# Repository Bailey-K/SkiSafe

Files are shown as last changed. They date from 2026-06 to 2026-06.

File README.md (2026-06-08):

# SkiSafe

Real-time alpine safety monitoring system. A wearable sensor node worn by the skier transmits telemetry over LoRa to a base-station hub at the lodge, which stores data in SQLite and serves a live web dashboard.

---

## System Architecture

```
Wearable (LoPy4)
  sensors → wearable.py → LoRa TX
                                  ↓
                          Hub LoPy4 (receiver.py)
                          LoRa RX → USB serial
                                  ↓
                          Raspberry Pi
                          reader.py → SQLite DB
                          app.py    → Flask dashboard
```

### Wearable Node

Pycom LoPy4 standalone (no expansion board), battery-powered via Adafruit PowerBoost 1000C. Reads sensors every loop and transmits a JSON packet over LoRa every 5 seconds (2 seconds at alert level 2+).

**Sensors:**

- MPU-6050 IMU — fall detection and immobility monitoring
- BH1750 light sensor — burial detection (sudden darkness after fall)
- NTC thermistor — skin temperature / hypothermia risk
- u-blox NEO-6M GPS — coordinates, speed, altitude

**Outputs:**

- RGB LEDs (alert state indicator)
- Passive piezo buzzer (alert audio)
- Tactile button (local alert dismiss)

### Hub Node

Pycom LoPy4 in a Pytrack expansion board, connected via USB to the Raspberry Pi. Runs `receiver.py` — listens for LoRa packets and prints them to serial.

### Raspberry Pi

Runs two processes (managed via tmux):

- `reader.py` — reads serial from the hub LoPy4, parses JSON telemetry, writes to SQLite
- `app.py` — Flask web dashboard served locally (and optionally via ngrok tunnel)

---

## Alert Levels

| Level  | Trigger | Response |
| --- | --- | --- |
| **L0** | Normal | Green LED steady, silent |
| **L1** | Low battery / cold skin / immobility 30s | Yellow LED, short pip every 2s |
| **L2** | Fall detected / immobility 60s | Red LED, urgent beep, dashboard warning |
| **L3** | L2 unacknowledged for 60s / burial / extreme cold | SOS flash + rapid beep, dashboard SOS, email alert |

Button press or hub ACK clears the buzzer and fall latch at any level.

---

## Repository Structure

```
├── Wearable/
│   ├── wearable.py                   # Production firmware (flash as main.py)
│   └── Component-Testing/
│       ├── hardware_test.py          # Full bring-up validation (PASS/FAIL/WARN)
│       ├── bh1750_test.py
│       ├── mpu6050_test.py
│       ├── ntc_test.py
│       ├── gps_lora_test.py
│       ├── sender_lora_test.py
│       └── receiver_lora_test.py
│
├── Hub/
│   ├── receiver.py                   # Runs on hub LoPy4 — LoRa RX → serial
│   ├── reader.py                     # Runs on Pi — serial → SQLite
│   ├── app.py                        # Runs on Pi — Flask dashboard
│   ├── requirements.txt
│   ├── templates/
│   │   ├── dashboard.html
│   │   └── review.html
│   └── scripts/
│       ├── start_hub.sh
│       ├── stop_hub.sh
│       ├── status_hub.sh
│       └── update-skisafe.sh
│
├── Hardware/
│   ├── pinout_mapping.md             # Full pin reference + circuit details
│   └── breadboard_layout.md         # Breadboard wiring guide
│
└── CAD/
    ├── v1/                           # SolidWorks + STEP files, version 1
    └── v2/                           # SolidWorks + STEP files, version 2
```

---

## Flash Commands

**Wearable firmware:**

```
uvx mpremote connect COM10 cp Wearable/wearable.py :main.py + reset + repl
```

**Hub receiver (one-time, run from project root):**

```
uvx mpremote connect /dev/ttyACM0 cp Hub/receiver.py :main.py + reset
```

---

## Hub Setup (Raspberry Pi)

```bash
# Install dependencies
pip install -r Hub/requirements.txt

# Start both processes in tmux
tmux new-session -d -s reader 'python3 ~/skisafe/reader.py'
tmux new-session -d -s app    'python3 ~/skisafe/app.py'

# Or use the helper scripts
bash Hub/scripts/start_hub.sh
bash Hub/scripts/status_hub.sh
```

Dashboard runs at `http://<pi-ip>:5000`.

---

## Hardware Notes

- **Power:** PowerBoost 1000C 5V → LoPy4 VIN only. All sensors run from LoPy4 3V3. Never connect 5V to any sensor or GPIO pin.
- **LoRa conflict:** P5–P12 on the LoPy4 conflict with the internal LoRa SPI bus and must not be used as GPIO outputs. Use P2–P4 and P21–P23 instead.
- **I2C:** MPU-6050 @ 0x68 (AD0→GND), BH1750 @ 0x23 (ADDR→3V3 via 10kΩ). Shared bus on P9/P10.
- **GPS:** NEO-6M — 3.3V only. One module was destroyed by 5V exposure.

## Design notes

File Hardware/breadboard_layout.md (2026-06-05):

# SkiSafe — Breadboard-Specific Layout & Wiring Guide

## SMALL BOARD — 30 Columns

### Component Placement Overview

| Component | Header row(s) | Columns  | Notes |
| --- | --- | --- | --- |
| LoPy4 | **c** (top header) and **h** (bottom header) | 1 – 14 | Module body spans rows c → h across the gap |
| 100 kΩ resistor #1 (BAT top) | **b** (top half) | 15 & 18  | Legs at b15 and b18, two-hole gap (cols 16–17 empty). b15 = BAT+ input. b18 = P15 midpoint. No polarity. |
| 100 kΩ resistor #2 (BAT bottom) | **b** (top half) | 18 & 21  | Legs at b18 and b21, two-hole gap (cols 19–20 empty). b18 = P15 midpoint (shared with R1). b21 = GND. No polarity. |
| Adafruit PowerBoost 1000C | **a** (pins in top half) | 23 – 30  | USB charging connector end at col 30; 5V out at col 23 |
| USB-to-UART adapter | **f** (pins in bottom half) | ~25 – 30 | TXD at **f28** (use h28), GND at **f29** (use h29). RXD is adjacent — check silkscreen. |

> **Wiring access rule — important:**  
> The LoPy4 module body physically covers rows **d, e** (top half) and **f, g** (bottom half) in cols 1–14.  
> Those rows are inaccessible for wiring under the module.  
> • To connect to the **top header** (row c): place jumper wires in rows **a or b**, same column.  
> • To connect to the **bottom header** (row h): place jumper wires in rows **i or j**, same column.  
> • PowerBoost pins are in row a — use rows **b, c, d, or e** (same column) for wire connections.  
> • USB-UART pins are in row f — use rows **g or h (cols 15–30 only)** for wire connections.

> **Power rule reminder:** PowerBoost 5V → LoPy4 VIN only.  
> LoPy4 3V3 output → large board (+) rail → all sensors. Never connect 5V to sensors.

---

### LoPy4 — Pin Reference Table

The LoPy4 sits directly in the breadboard. Header pins: **top header in row c, bottom header in row h**.

| Col | Row c — Top Header | Row h — Bottom Header | Active Signal / Notes |
| --- | --- | --- | --- |
| 1 | P13 ⚠ input-only | P12 | (spare) |
| 2 | **P14** ⚠ input-only (NTC ADC)  | P11 | NTC ADC in ← large board / (spare) |
| 3 | **P15** ⚠ input-only (batt ADC) | **P10** (I2C SCL) | Batt ADC in ← large board / SCL → large board (hardware SCL) |
| 4 | P16 ⚠ input-only | **P9** (I2C SDA) | SDA → large board (hardware SDA) |
| 5 | P17 ⚠ input-only | P8 | (spare) |
| 6 | P18 ⚠ input-only | P7 | (spare) |
| 7 | **P19** (GPS UART1 RX) | P6 | GPS NMEA in ← large board / (spare) |
| 8 | P20 | P5 | (spare) |
| 9 | **P21** (buzzer out) | **P4** (red LED out) | Buzzer → large board / Red LED → large board |
| 10  | **P22** (button in) | **P3** (yellow LED out)  | Button ← large board / Yellow LED → large board |
| 11  | P23 | **P2** (green LED out) | (spare) / Green LED → large board |
| 12  | **3V3** (output) | **P1** (UART0 TX0) | 3V3 → T+ rail / P1 → USB-UART RXD |
| 13  | GND | **P0** (UART0 RX0) | Ground → T− rail / P0 ← USB-UART TXD |
| 14  | **VIN** | **RST** | 5V in from PowerBoost / reset |

> ⚠ **P13–P18 are input-only** (ESP32 GPIO34–39 — no internal pullup/pulldown, cannot be used as outputs). P14 and P15 are used as ADC inputs only — this is correct and intentional.
> **P9 = hardware SDA, P10 = hardware SCL.** I2C is initialised on these pins in firmware. P0/P1 = UART0 serial console (REPL + flashing). P5–P8, P11, P12 are spare (avoid using as GPIO outputs — these pins conflict with the LoPy4 internal LoRa SPI bus). P23 is spare.

> Confirm all pin positions against your board's silkscreen before wiring — pin order can vary by board revision.

**Wire access summary for LoPy4 pins:**

| Header | Pin row | Connect jumpers in |
| --- | --- | --- |
| Top header | c | Rows **a** or **b** (same column) |
| Bottom header | h | Rows **i** or **j** (same column) |

---

### PowerBoost 1000C — Pin Reference Table

Positioned in the **top half** (rows a–e), **cols 23–30**. Pins insert into row **a**. USB-C charging connector end sits at col 30.

| Col | Row a | Signal | From | To |
| --- | --- | --- | --- | --- |
| 23  | **5V** (out) | Boosted 5V to LoPy4 VIN | **b23** | **b14** (LoPy4 VIN, top half col 14) |
| 24  | GND | PowerBoost ground | **b24** | T− rail |
| 25  | EN | Enable — leave open | — | — |
| 26  | GND | Ground (BAT side) | **b26** | T− rail |
| 27  | LBO | Low battery indicator — leave open | — | — |
| 28  | VS | Battery voltage sense — leave open | — | — |
| 29  | **BAT** | LiPo+ → battery divider | **b29** | **a15** (R1 top leg — use a15 since b15 has the resistor) |
| 30  | USB | Charging input (USB-C) | plug cable in | — |

> The LiPo cell connects via the JST-PH connector on the PowerBoost board — the BAT pin at a29 is the same electrical node as solder pad on the board edge, accessible at b29.

---

### USB-to-UART Adapter — Pin Reference Table

Positioned in the **bottom half** (rows f–j). Pins insert into row **f**. Use rows **g, h, i, or j** in the same column as connection points.

| Col | Row f | Signal | From | To | Purpose |
| ----- | --- | --- | --- | --- | --- |
| 27 | **RXD** | Adapter receive (data **from** LoPy4) | **h27** | **i12** (LoPy4 P1 — UART0 TX0) | See serial print output in terminal |
| 28 | **TXD** | Adapter transmit (data **to** LoPy4)  | **h28** | **i13** (LoPy4 P0 — UART0 RX0) | Send REPL commands to LoPy4 |
| 29 | **GND** | Ground | **h29** | T− rail | Common ground |
| other | 3V3 / 5V / CTS | — | — | **Leave unconnected** | LoPy4 is powered by PowerBoost independently |

> **RXD ← P1 (UART0 TX0):** This wire lets you see everything the LoPy4 prints — sensor readings, errors, REPL/debug output. Open any serial terminal (e.g. PuTTY, Arduino Serial Monitor) at **115200 baud** on your USB-UART's COM port.
> 
> **TXD → P0 (UART0 RX0):** Full bidirectional REPL — type commands and see responses. UART0 *is* the LoPy4's REPL/programming console, so this is also the port mpremote uses to upload code. No GPS conflict: GPS uses UART1 (P19) and the serial console uses UART0 (P0/P1). Both work simultaneously, permanently, no swapping needed.
> 
> **Flashing (uploading code):** Works over this same adapter. Because UART0 is the REPL console, mpremote uploads through P0/P1 — no separate USB needed. Example (run from the project root): `uvx mpremote connect COM10 cp "Wearable/Code/Component-Testing/Full-Hardware_Test.py" :main.py + reset + repl`.
> 
> **Wire routing:** f27 and f29 are occupied by the adapter pins — use h27, h28, h29 (same bottom-half column, same node) as your jumper wire insertion points.  
> P0 and P1 are on the **bottom header, cols 13 and 12** — use i13 (P0) and i12 (P1) as insertion points.  
> In firmware: nothing to initialise — print() output and the REPL/mpremote both use the default UART0 console automatically.

---

### Battery Voltage Divider — on the Small Board

> Two 100 kΩ resistors at cols 15–21 (row b). R1 legs at b15 and b18; R2 legs at b18 and b21. b15 is occupied by the resistor leg — wire to **a15** (same node). Midpoint at b18 → P15 (wire S5). R2 far end at b21 is occupied — wire to **c21** (same node) → GND (wire S6). See S1–S11 in the Complete Wire Map.

---

## LARGE BOARD — 63 Columns (split into two halves for readability)

### Component Placement Overview

| Component | Type | Insert row | Columns | Orientation / notes |
| --- | --- | --- | --- | --- |
| MPU-6050 (GY-521) | 8-pin single-row breakout | **c** (top half) | 2 – 9 | Col 2=INT, 3=ADD, 4=XCL, 5=XDA, 6=SDA, 7=SCL, 8=GND, 9=VCC. ADD (col 3) wired to GND for address 0x68. Wires in row e. |
| BH1750 (GY-302) | 5-pin single-row breakout | **c** (top half) | 12 – 16 | Col 12=VCC, 13=SCL, 14=SDA, 15=ADD, 16=GND. ADD (col 15) connected to B+ (3V3) rail via a 10 kΩ current-limiting resistor to bypass an internal board short. Sets hardware address to 0x23. |
| NEO-6M GPS module | 4-pin header (large PCB overhangs) | **a** (top half) | 21 – 24 | Col 21=VCC, 22=RX (leave open), 23=TX, 24=GND. Antenna faces back. Wires in row e. |
| 10 kΩ fixed resistor (NTC series) | Through-hole resistor | **a** (top half) | 31 & 33 | Legs in a31 and a33. Bridges col 32. No polarity. The junction at col 31 is the ADC node shared with the NTC. |
| 10 kΩ NTC thermistor | Through-hole thermistor | **c** (top half) | 31 – 32 | Legs in c31 and c32. Col 31 = ADC node (electrically joined to a31 — same column, same half). Col 32 leg wired to GND. Body extended on a short lead for wrist contact. |
| Green LED | 5 mm LED (3 holes wide) | **h** (bottom half) | 48, 49 (body), 50 | **Anode (long leg) at h50**, cathode (short leg) at h48. Body over h49 (empty). Signal wire h50 ← small board i8 (P5). Resistor j48 → B− rail. |
| Yellow LED | 5 mm LED (3 holes wide) | **h** (bottom half) | 44, 45 (body), 46 | **Anode (long leg) at h46**, cathode (short leg) at h44. Body over h45 (empty). Signal wire h46 ← small board i7 (P6). Resistor j44 → B− rail. |
| Red LED | 5 mm LED (3 holes wide) | **h** (bottom half) | 40, 41 (body), 42 | **Anode (long leg) at h42**, cathode (short leg) at h40. Body over h41 (empty). Signal wire h42 ← small board i6 (P7). Resistor j40 → B− rail. |
| 220 Ω resistor — green LED | Through-hole resistor | **j** (bottom half) | 48 | j48 → B− rail. No polarity. |
| 220 Ω resistor — yellow LED | Through-hole resistor | **j** (bottom half) | 44 | j44 → B− rail. No polarity. |
| 220 Ω resistor — red LED | Through-hole resistor | **j** (bottom half) | 40 | j40 → B− rail. No polarity. |
| Piezo buzzer | Passive piezo disc | **a** and **c** (top half, diagonal) | 55 (+), 57 (−) | Positive (+) leg at **a55**, negative (−) leg at **c57**. Diagonal placement due to body shape. Both legs in top half — no gap crossing needed. |
| Tactile button | Momentary switch | **i** (bottom half) | 59 & 61 | Legs at **i59** (GND) and **i61** (signal). Wires connect at j59 (GND) and j61 (signal). Pressing bridges cols 59 and 61. |

> **Polarity reminders:**  
> — LEDs: long leg = anode (+), short leg = cathode (−). Inserting backwards = no light, no damage.  
> — Buzzer: marked (+) = positive. Inserting backwards = no sound.  
> — Resistors and NTC: no polarity — insert either way.  
> — GPS module: **3.3V VCC only** — double check before powering on.

---

### Component-by-Component Wiring

### MPU-6050 — Cols 2–9, Row c

The MPU-6050 has **8 pins in a single row**. Insert into row **c**. Wires connect in row **e** (same top-half node).

| From | To | Signal |
| --- | --- | --- |
| 3V3 rail (B+) | **e9** (MPU VCC) | 3.3V power |
| **e8** (MPU GND) | GND rail (B−) | Ground |
| **e7** (MPU SCL) | **c13** (BH SCL — shared channel to LoPy4 P10) | I2C clock via daisy-chain |
| **e6** (MPU SDA) | **c14** (BH SDA — shared channel to LoPy4 P9)  | I2C data via daisy-chain  |
| c5 XDA | — | Not connected |
| c4 XCL | — | Not connected |
| **e3** (MPU ADD) | GND rail (B−) | Set I2C address 0x68 |
| c2 INT | — | Not connected |

---

### BH1750 — Cols 12–16, Row c

The BH1750 has **5 pins in a single row**. Insert into row **c**. Wires connect in row **e** (same top-half node).

| From | To | Signal |
| --- | --- | --- |
| 3V3 rail (B+) | **e12** (BH VCC) | 3.3V power |
| **e13** (BH SCL) | Small board **i3** (P10, SCL) | I2C clock |
| **e14** (BH SDA) | Small board **i4** (P9, SDA)  | I2C data |
| **3V3** rail (B+) via 10 kΩ Resistor | e15 (BH ADD) | Safely address pull-up (yields address 0x23) |
| **e16** (BH GND) | GND rail (B−) | Ground |

> **I2C daisy-chain:** The inter-board wires from the LoPy4 (I3/I4) land at c14 (BH SDA) and c13 (BH SCL). Jumper wires L4/L5 connect those same columns at e6 (MPU SDA) and e7 (MPU SCL) — placing both sensors on the same I2C lines. The BH1750 output wires (e13→i3, e14→i4) carry the signal back to the LoPy4.
> The breakout boards include on-board pull-up resistors — do not add extra ones.

---

### NEO-6M GPS Module — Cols 21–24, Row a

Wires connect in row **e** (node in row a).

| From | To | Signal |
| --- | --- | --- |
| 3V3 rail (B+) | **e21** (GPS VCC) | 3.3V power **(NEVER 5V)** |
| a22 GPS RX | — | Leave unconnected |
| **e23** (GPS TX)  | Small board **b7** (LoPy4 P19) | GPS NMEA data |
| **e24** (GPS GND) | GND rail (B−) | Ground |

> **⚠ 3.3V only.** Double-check before powering on.

---

### NTC Thermistor Circuit — Cols 31–33

This is a voltage divider built from two components: a fixed 10 kΩ resistor and the NTC thermistor. The NTC is fragile — handle legs carefully and don't flex them repeatedly.

```
  Circuit:  3V3 → [10kΩ fixed] → P14 (ADC node) → [10kΩ NTC] → GND
```

**Physical layout:** The fixed resistor sits in row **a** (legs at a31 and a33, bridging col 32). The NTC sits in row **c** (legs at c31 and c32). Because rows a–e in the same column are all connected, **a31 and c31 are the same electrical node** — that junction is the P14 ADC midpoint. No bridge wire needed between them; the breadboard does it internally.

| From | To | Signal | Notes |
| --- | --- | --- | --- |
| 3V3 rail (B+) | **b33** (resistor top leg) | 3.3V supply into divider | a33 = b33 (same top-half column) |
| **b31** (ADC node / resistor bottom leg = NTC top leg) | Small board **b2** (LoPy4 P14) | NTC ADC signal | a31 = b31 = c31 — all same node  |
| **b32** (NTC bottom leg) | GND rail (B−) | Divider GND | c32 = b32 — same node |
| Resistor legs | a31 & a33 | 10 kΩ fixed (bridges col 32) | — |
| Thermistor legs | c31 & c32 | 10 kΩ NTC | — |

---

### LED Bank — Cols 40–49

The 220 Ω resistor sits between the cathode and the B− GND rail 

#### Green LED (P2) — Cols 48, & 50

| From | To | Signal |
| --- | --- | --- |
| Small board **i11** (P2) | Large board **h50** | P2 GPIO signal |
| **h50** | — | LED anode, long leg inserted here |
| **h48** | — | LED cathode, short leg inserted here |
| **j48** | **B− rail** | 220 Ω resistor (cathode → GND) |

#### Yellow LED (P3) — Cols 44, & 46

| From | To | Signal |
| --- | --- | --- |
| Small board **i10** (P3) | Large board **h46** | P3 GPIO signal |
| **h46** | — | LED anode, long leg inserted here |
| **h44** | — | LED cathode, short leg inserted here |
| **j44** | **B− rail** | 220 Ω resistor (cathode → GND) |

#### Red LED (P4) — Cols 40, & 42

| From | To | Signal |
| --- | --- | --- |
| Small board **i9** (P4) | Large board **h42** | P4 GPIO signal |
| **h42** | — | LED anode, long leg inserted here |
| **h40** | — | LED cathode, short leg inserted here |
| **j40** | **B− rail** | 220 Ω resistor (cathode → GND) |

> **LED polarity:** Long leg = anode (+). Short leg = cathode (−).

---

### Piezo Buzzer — Col 55 (+), Col 57 (−), diagonal

Direct GPIO drive from P21 at 3.3V. Placed diagonally.

| From | To | Signal |
| --- | --- | --- |
| Small board **b9** (LoPy4 P21) | **b55** (= a55, buzzer positive) | P21 GPIO signal |
| **b57** (= c57, buzzer negative) | GND rail (B−) | Ground |

---

### Dismiss Button — Cols 59 & 61

Tactile momentary switch, active LOW with PULL_UP. Entirely in the bottom half.

| From | To | Signal |
| --- | --- | --- |
| Small board **b10** (LoPy4 P22) | **j61** (button signal leg) | P22 GPIO signal |
| **j59** (button GND leg) | B− rail | Ground (active-LOW when pressed) |

---

## Complete Wire Map

Every wire in the system listed with exact breadboard reference.

### Small Board — Internal Wires

| # | From | To | Signal |
| --- | --- | --- | --- |
| S1  | **b23** (PowerBoost 5V)  | **b14** (LoPy4 VIN) | 5V power |
| S2  | **b24** (PowerBoost GND) | T− rail | Ground |
| S3  | **b26** (PowerBoost GND) | T− rail | Ground |
| S4  | **b29** (PowerBoost BAT) | **a15** (R1 top leg — b15 is occupied by the resistor, a15 is same node) | LiPo+ into bat divider |
| S5  | **a18** (R1/R2 midpoint) | **b3** (LoPy4 P15) | Battery ADC signal |
| S6  | **c21** (R2 bottom leg)  | T− rail | Divider GND |
| S7  | **b12** (LoPy4 3V3) | T+ rail | 3.3V supply |
| S8  | **b13** (LoPy4 GND) | T− rail | Ground |
| S9  | **h29** (USB-UART GND) | T− rail | Ground |
| S10 | **h27** (USB-UART RXD) | **i12** (LoPy4 P1, UART0 TX0) | Serial + REPL output — LoPy4 → terminal |
| S11 | **h28** (USB-UART TXD) | **i13** (LoPy4 P0, UART0 RX0) | REPL / flash upload — terminal → LoPy4  |

### Inter-Board Wires (Small Board → Large Board)

| # | From (small board) | To (large board) | Signal |
| --- | --- | --- | --- |
| I1  | T+ rail | B+ (3V3) rail | 3.3V power |
| I2  | T− rail | GND (B−) rail | Ground |
| I3  | **i4** (LoPy4 P9, SDA) | **c14** (BH SDA), daisy-chained over to**e6** (MPU SDA) | I2C data |
| I4  | **i3** (LoPy4 P10, SCL) | **c13** (BH SCL), daisy-chained over to**e7** (MPU SCL) | I2C clock |
| I5  | **b7** (LoPy4 P19, GPS RX) | **e23** (GPS TX) | GPS NMEA |
| I6  | **b2** (LoPy4 P14, NTC ADC) | **b31** (NTC ADC node) | NTC temperature |
| I7  | **i11** (LoPy4 P2, green LED)  | **h50** (green LED anode) | Green LED signal  |
| I8  | **i10** (LoPy4 P3, yellow LED) | **h46** (yellow LED anode) | Yellow LED signal |
| I9  | **i9** (LoPy4 P4, red LED) | **h42** (red LED anode) | Red LED signal |
| I10 | **b9** (LoPy4 P21, buzzer) | **b55** (= a55, buzzer positive) | Buzzer drive |
| I11 | **b10** (LoPy4 P22, button) | **j61** (button leg 1) | Button signal |

### Large Board — Internal Wires

| # | From | To | Signal |
| --- | --- | --- | --- |
| L1  | B+ (3V3) rail | **e9** (MPU VCC) | 3.3V to MPU-6050 |
| L2  | **e8** (MPU GND) | B− rail | MPU-6050 ground |
| L3  | **e3** (MPU ADD) | B− rail | MPU I2C address = 0x68 |
| L4  | **e6** (MPU SDA) | **c14** (BH SDA) | SDA daisy-chain between sensors |
| L5  | **e7** (MPU SCL) | **c13** (BH SCL) | SCL daisy-chain between sensors |
| L6  | B+ (3V3) rail | **e12** (BH VCC) | 3.3V to BH1750 |
| L7  | **e15** (BH ADD) | B+ (3V3) rail via 10k Ω Resistor | Safety bypass: locks BH1750 address to 0x23 |
| L8  | **e16** (BH GND) | B− rail | BH1750 ground |
| L9  | B+ (3V3) rail | **e21** (GPS VCC) | 3.3V to GPS ⚠ NEVER 5V |
| L10 | **e24** (GPS GND) | B− rail | GPS ground |
| L11 | B+ (3V3) rail | **b33** (NTC fixed R top) | 3.3V into NTC divider |
| L12 | **b32** (NTC GND leg) | B− rail | NTC divider ground |
| L13 | **j40** (red LED cathode) | B− rail | Red LED GND return via 220 Ω |
| L14 | **j44** (yellow LED cathode) | B− rail | Yellow LED GND return via 220 Ω |
| L15 | **j48** (green LED cathode)  | B− rail | Green LED GND return via 220 Ω |
| L16 | **b57** (buzzer negative) | B− rail | Buzzer ground |
| L17 | **j59** (button GND leg) | B− rail | Button ground (active-LOW) |

> **Totals: 11 small-board internal + 11 inter-board + 17 large-board internal = 39 wires.**
> L4 and L5 are the only inter-sensor jumpers on the large board (I2C daisy-chain).
> Battery divider is fully on the small board — no inter-board wires for P15 or BAT.

---

## Pre-Power Checklist

Before applying power for the first time:

- [ ] LoPy4 VIN connected to PowerBoost 5V — **not** to 3V3
- [ ] GPS VCC connected to 3V3 rail — **not** to 5V or LoPy4 VIN
- [ ] MPU-6050 AD0 connected to GND (not floating)
- [ ] NTC circuit: 3V3 → 10kΩ → P14 node → NTC → GND (NTC on bottom)
- [ ] Battery divider: BAT+ → 100kΩ → P15 node → 100kΩ → GND
- [ ] All three LED cathodes (short leg) to GND rail
- [ ] LED anodes (long leg) away from GND, toward resistors
- [ ] Buzzer polarity: (+) to P21 (b9), (−) to GND
- [ ] Button: P22 (b10) → j61 (signal leg); j59 → GND
- [ ] Large board B+ connected to small board B+ (3V3 inter-board)
- [ ] Large board B− connected to small board B− (GND inter-board)
- [ ] I2C: P9 (i4) → SDA daisy-chain (c14 ↔ e6); P10 (i3) → SCL daisy-chain (c13 ↔ e7)
- [ ] USB-UART on P0/P1 (UART0 console) — GPS on P19 (UART1) — no conflict
- [ ] BH1750 ADD connected to 3V3 rail via 10 kΩ resistor (Bypasses address pin ground short)
- [ ] I2C scan returns `[0x23, '0x68']` before flashing production firmware

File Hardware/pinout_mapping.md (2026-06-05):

# SkiSafe — Hardware Pinout & Wiring Reference
**Board:** Pycom LoPy4 (standalone, no expansion board)  
**Runtime:** Pycom MicroPython 1.20.2.r6  

---

## ⚠ Critical Power Rules

> **The 5V rail (PowerBoost 1000C output) connects ONLY to LoPy4 VIN.**  
> Every sensor, module, LED, and buzzer runs from LoPy4 **3V3** only.  
> Connecting any LoPy4 GPIO or sensor directly to 5V WILL destroy it.  
> The NEO-6M GPS was destroyed once by 5V exposure — do not repeat.

> **Never disconnect or reconnect sensors while powered.**  
> The LoPy4 ADC inputs are not 5V tolerant and have limited ESD protection.

---

## LoPy4 Pin Assignment — Complete

| LoPy4 Pin | Direction | Connected To | Signal | Notes |
|---|---|---|---|---|
| **P2**  | Output | Green LED → 220 Ω → GND | Status LED green | Alert level 0 = normal |
| **P3**  | Output | Yellow LED → 220 Ω → GND | Status LED yellow | Alert level 1 = warning |
| **P4**  | Output | Red LED → 220 Ω → GND | Status LED red | Alert level 2 = fall / SOS |
| **P9**  | I2C SDA | MPU-6050 SDA + BH1750 SDA | I2C data | Hardware SDA. Shared bus — both devices on same wires. |
| **P10** | I2C SCL | MPU-6050 SCL + BH1750 SCL | I2C clock | Hardware SCL. Shared bus. |
| **P21** | Output | Piezo buzzer (+) → GND | Alert buzzer | Active HIGH. Non-blocking pattern in firmware. |
| **P22** | Input  | Tactile button → GND | Alert dismiss | `PULL_UP`, active LOW. Idle = HIGH. Press = LOW. |
| **P14** | ADC in | NTC thermistor (GND-side of divider) | Skin temperature | `ATTN_11DB` (0–3.6V). 10 kΩ NTC from P14→GND, 10 kΩ series from 3V3→P14. |
| **P15** | ADC in | Battery divider midpoint | Battery % monitor | `ATTN_11DB`. 100 kΩ from LiPo+→P15, 100 kΩ from P15→GND. V_pin = V_bat/2. |
| **P19** | UART1 RX | NEO-6M GPS TX | GPS NMEA receive | Data flows GPS→LoPy4. |
| **P0**  | UART0 RX0 | USB-UART adapter TXD | Serial console in | REPL input / mpremote code upload, 115200 baud. |
| **P1**  | UART0 TX0 | USB-UART adapter RXD | Serial console out | REPL + print()/debug output, 115200 baud. |

> ⚠ **P13–P18 are input-only** (ESP32 GPIO34–39 — no internal pullup/pulldown, cannot drive outputs). P14 and P15 are intentionally used as ADC inputs only.
> ⚠ **P5–P12 conflict with the LoPy4 internal LoRa SPI bus** — do not use as GPIO outputs. Initialising any of these as Pin.OUT silently breaks LoRa TX (confirmed by hardware testing June 2026). Use P2–P4, P21–P23 for GPIO outputs instead.

### Firmware declaration reference
```python
# I2C shared bus — hardware pins (MPU-6050 @ 0x68, BH1750 @ 0x23)
i2c = I2C(0, pins=('P9', 'P10'))

# GPS UART1 — P19=RX only
gps_uart = UART(1, baudrate=9600, pins=(None, 'P19'))

# Debug / REPL console — default UART0 on P0 (RX0) / P1 (TX0), 115200 baud.
# Nothing to initialise: print() output and the REPL/mpremote use UART0 automatically.

# ADC channels
adc       = ADC()
ntc_chan  = adc.channel(pin='P14', attn=ADC.ATTN_11DB)
batt_chan = adc.channel(pin='P15', attn=ADC.ATTN_11DB)

# Outputs
buzzer     = Pin('P21', mode=Pin.OUT, value=0)
led_green  = Pin('P2',  mode=Pin.OUT, value=0)
led_yellow = Pin('P3',  mode=Pin.OUT, value=0)
led_red    = Pin('P4',  mode=Pin.OUT, value=0)

# Input
button = Pin('P22', mode=Pin.IN, pull=Pin.PULL_UP)   # active LOW
```

---

## I2C Bus — Shared Devices

| Device | I2C Address | ADDR Pin | Pull-up Resistors |
|---|---|---|---|
| MPU-6050 (IMU) | `0x68` | AD0 → GND | Breakout has on-board 4.7 kΩ pull-ups on SDA/SCL |
| BH1750 (Light) | `0x46` | ADDR → 3V3 | Breakout has on-board pull-ups |

```
3V3 ──┬── MPU-6050 VCC              3V3 ──┬── BH1750 VCC
      │                                   │
P9  ──┼── MPU-6050 SDA              P9  ──┼── BH1750 SDA
P10 ──┼── MPU-6050 SCL              P10 ──┼── BH1750 SCL
      │                                   │
GND ──┴── MPU-6050 GND              GND ──┴── BH1750 GND
GND ───── MPU-6050 AD0              3V3 ───── BH1750 ADDR
```

> Both sensors share the same SDA and SCL lines. The MPU-6050 SDA/SCL wires connect into the same nodes as the BH1750 SDA/SCL — the breadboard/perfboard junction carries signal from both sensors to the LoPy4 on P9/P10.

Verify I2C bus with:
```python
from machine import I2C
i2c = I2C(0, pins=('P9', 'P10'))
print([hex(d) for d in i2c.scan()])
# Expected: ['0x46', '0x68']
```

---

## GPS Module (GY-NEO6MV2 / u-blox NEO-6M)

| GPS Pin | Connects To | Notes |
|---|---|---|
| VCC | LoPy4 **3V3** | **3.3V ONLY — 5V will destroy the module (confirmed once).** |
| GND | GND | Common ground |
| TX | LoPy4 **P19** | GPS sends NMEA sentences → LoPy4 UART1 RX |
| RX | **LEAVE OPEN** | No commands sent to GPS. |

```
NEO-6M module
┌──────────┐
│ VCC ─────┼──── 3V3
│ GND ─────┼──── GND
│ TX  ─────┼──── P19  (LoPy4 UART1 RX)
│ RX  ─────┼──── (nothing)
└──────────┘
```

**UART config:** 9600 baud, 8N1  
**Sentences parsed:** `$GPRMC` / `$GNRMC` (position, speed, validity), `$GPGGA` / `$GNGGA` (altitude, satellite count)  
**Fix indicator:** TIMEPULSE LED on the breakout board blinks at 1 Hz once a fix is acquired  
**Cold start time:** 1–15 minutes outdoors; indoor fix with ceramic patch antenna is unreliable

---

## NTC Thermistor Circuit (Skin Temperature — P14)

```
3V3 ──── 10 kΩ (series, fixed) ──── P14 (ADC) ──── 10 kΩ NTC ──── GND
```

- NTC is on the **GND side** (bottom) of the voltage divider  
- Higher temperature → lower NTC resistance → lower voltage at P14 → lower ADC raw value  
- `ATTN_11DB` sets full-scale ≈ 3.6V, raw range 0–4095  
- Steinhart-Hart Beta: **B = 3950**, T₀ = 25°C, R₀ = 10 kΩ  
- Sentinel: raw ≤ 10 or ≥ 4085 → open/short detected → firmware returns −99.0°C  
- Valid skin range: approximately 15°C – 40°C in field use  
- NTC body sits against the inner wrist strap for skin contact

---

## Battery Monitor Circuit (P15)

```
LiPo+ (BAT pin) ──── 100 kΩ ──── P15 (ADC) ──── 100 kΩ ──── GND
```

- Equal-value divider: V_P15 = V_bat / 2  
- LiPo range: 3.3V (empty) → 4.2V (full) → P15 sees 1.65V → 2.10V  
- `ATTN_11DB` comfortably covers this range with no risk of exceeding 3.6V  
- Formula: `batt_pct = (V_bat − 3.3) / (4.2 − 3.3) × 100`, clamped 0–100  
- BAT pin is the output of the PowerBoost 1000C (same node as LiPo positive)

---

## LED Wiring

Each LED uses a **220 Ω** current-limiting series resistor.  
At 3.3V with a typical LED Vf ≈ 2.0V: I = (3.3 − 2.0) / 220 ≈ **6 mA** — safe for LoPy4 GPIO.

```
P2 ──── Green LED anode  ──── cathode ──── 220 Ω ──── GND
P3 ──── Yellow LED anode ──── cathode ──── 220 Ω ──── GND
P4 ──── Red LED anode    ──── cathode ──── 220 Ω ──── GND
```

| Alert Level | Meaning | LED State |
|---|---|---|
| 0 — Normal | All good | Green steady ON, Yellow OFF, Red OFF |
| 1 — Warning | Low battery / cold / immobility warning | Yellow steady ON, Green OFF, Red OFF |
| 2 — Alert | Fall detected / prolonged immobility | Red steady ON, Green OFF, Yellow OFF |
| 3 — SOS | Burial / extreme cold / fall + unconscious | Yellow rapid flash + Red rapid flash, Green OFF |

---

## Buzzer

```
P21 ──── Buzzer positive ──── Buzzer negative ──── GND
```

- Passive piezo, direct GPIO drive at 3.3V (no transistor needed at this current draw)  
- Non-blocking pattern controlled by `update_buzzer()` — uses timestamps, not `sleep()`

| Alert Level | Pattern | Cadence |
|---|---|---|
| 0 — Normal | Silent | — |
| 1 — Warning | Short pip | 100 ms ON / 1900 ms OFF |
| 2 — Fall | Urgent beep | 300 ms ON / 700 ms OFF |
| 3 — SOS | Rapid pulse | 200 ms ON / 200 ms OFF |

**Mute behaviour:** Physical button press OR hub LoRa ACK clears both the buzzer mute flag and the fall detection latch.

---

## Button (Alert Dismiss)

```
P22 ──── one terminal of button
GND ─── other terminal of button
```

- Internal `PULL_UP` enabled — idle state P11 = HIGH (1)  
- Press pulls P11 to GND → LOW (0)  
- Firmware uses 50 ms software debounce  
- Action: mutes buzzer, clears fall detection latch

---

## Power Architecture

```
LiPo cell (3.7V nominal, 1200–2000 mAh)
    │
    ▼
Adafruit PowerBoost 1000C
    │  ← USB-C input for charging (charges while running)
    │
    ├── 5V output ──────────────── LoPy4 VIN            ← ONLY 5V connection
    └── BAT pin ─── 100 kΩ ─── P15 (battery monitor)
                         └─── 100 kΩ ─── GND

LoPy4 VIN (5V) ──── LoPy4 onboard 3.3V regulator
                        │
                        ├── LoPy4 3V3 supply
                        ├── MPU-6050 VCC
                        ├── BH1750 VCC
                        ├── NEO-6M GPS VCC  ← 3.3V only
                        ├── 10 kΩ NTC series resistor (top of divider)
                        └── 100 kΩ battery divider (top resistor)
```

---

## Alert Escalation Logic (Firmware)

| Condition | Alert Level | Hub Action |
|---|---|---|
| Battery < 20% | L1 | Local warning only (no hub action) |
| Skin temp < 15°C | L1 | Local warning only |
| Immobile ≥ 30 s | L1 | Local warning only |
| Immobile ≥ 60 s | L2 | Hub shows ALERT, enables ACK button |
| Fall detected (latch 5 min) | L2 | Hub shows ALERT |
| Skin temp < 10°C | L3 | Hub sends SOS email |
| Burial (dark + immobile ≥ 60 s) | L3 | Hub sends SOS email |
| Fall + immobile ≥ 120 s | L3 | Hub sends SOS email |

**Fall latch:** Once a fall spike is detected, the alert holds at minimum L2 for 5 minutes even if the skier stands up.  
Only a physical button press or a hub LoRa ACK clears the latch early.

---

## LoRa Link (Wearable → Hub)

| Parameter | Value |
|---|---|
| Frequency | 915 MHz |
| Region plan | AU915 |
| Spreading factor | SF7 |
| Bandwidth | 125 kHz |
| Coding rate | 4/5 |
| Preamble | 8 symbols |
| TX power | Default (Pycom LoPy4 max ≈ 20 dBm) |
| Packet size | ~85–100 bytes (JSON) |
| Normal TX cadence | 5 seconds |
| Alert (L2+) TX cadence | 2 seconds |

**Packet format (short keys — matches reader.py KEY_MAP):**
```
{"i":"SK01","c":12,"st":28.3,"lx":1102.4,"la":-37.1522,"lo":146.4418,"al":1707.0,"sp":42.1,"a":0}
```

---

## Hub Node — LoPy4 in Pytrack

| Connection | Detail |
|---|---|
| USB | Pytrack USB-C → Raspberry Pi `/dev/ttyACM0` |
| Serial baud | 115200 |
| LoRa antenna | 915 MHz whip on **bottom-left U.FL** connector of LoPy4 |
| LoRa config | Identical to wearable (915 MHz AU915 SF7 BW_125KHz CR 4/5 preamble 8) |

The hub LoPy4 runs `receiver.py` — receives LoRa packets and prints them to serial in the format `reader.py` expects:
```
Received: {"i":"SK01","c":12,...}
RSSI: -72
SNR: 8.5
```

---

## Component I2C Address Reference

| Address | Device | Config |
|---|---|---|
| `0x68` | MPU-6050 IMU | AD0 → GND (default) |
| `0x69` | MPU-6050 (alt) | AD0 → 3V3 — not used |
| `0x46` | BH1750 light sensor | ADDR → 3V3 |
| `0x23` | BH1750 (alt) | ADDR → GND or floating — not used |

---

## Bill of Materials — Prototype

| Qty | Component | Value / Part | Notes |
|-----|---|---|---|
| 1 | Pycom LoPy4 | — | Standalone — no expansion board |
| 1 | MPU-6050 breakout | GY-521 | I2C, AD0 → GND |
| 1 | BH1750 breakout | GY-302 | I2C, ADDR → 3V3 |
| 1 | GPS module | GY-NEO6MV2 (u-blox NEO-6M) | **3.3V VCC only** |
| 1 | NTC thermistor | 10 kΩ, B=3950 | Skin contact sensor |
| 1 | Fixed resistor | 10 kΩ | NTC series / divider top |
| 2 | Fixed resistor | 100 kΩ | Battery voltage divider |
| 3 | Fixed resistor | 220 Ω | LED current limiting |
| 1 | Green LED | 3mm or 5mm | Status level 0 |
| 1 | Yellow LED | 3mm or 5mm | Status level 1 |
| 1 | Red LED | 3mm or 5mm | Status level 2 |
| 1 | Piezo buzzer | Passive, 3V–5V | P21 direct drive |
| 1 | Tactile button | Momentary NO | Dismiss / mute |
| 1 | Adafruit PowerBoost 1000C | — | USB-C charge + 5V boost |
| 1 | LiPo battery | 3.7V, 1200–2000 mAh | Connected to PowerBoost |
| 1 | LoRa antenna | 915 MHz whip | On LoPy4 U.FL |
| 1 | USB-to-UART adapter | CP2102 or similar | UART0 console / REPL / flashing (P0/P1) |

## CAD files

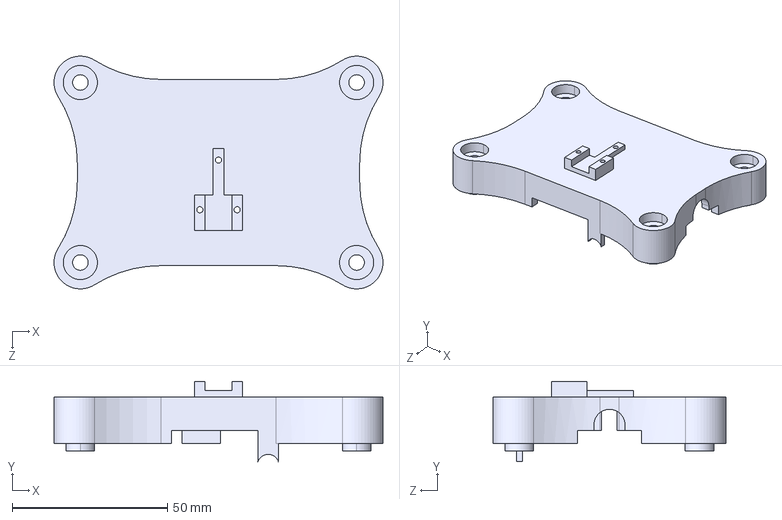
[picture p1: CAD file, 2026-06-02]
CAD/v2/SkiSafe 02 - Back.STEP
106.0 x 25.8 x 75.0 mm

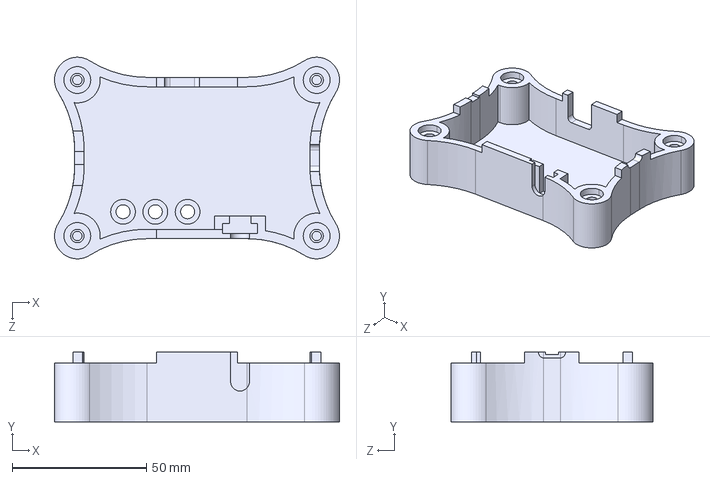
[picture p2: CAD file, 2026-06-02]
CAD/v2/SkiSafe 02 - Front.STEP
106.0 x 26.0 x 75.0 mm

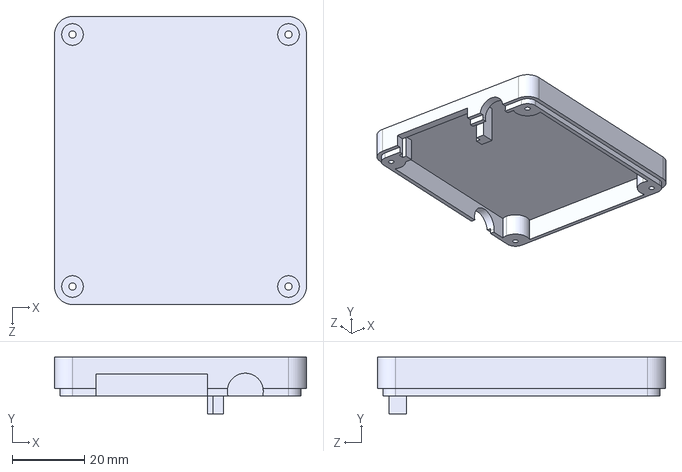
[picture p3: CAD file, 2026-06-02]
CAD/v2/SkiSafe CamelBack 02 - BASE.STEP
70.0 x 15.8 x 80.0 mm

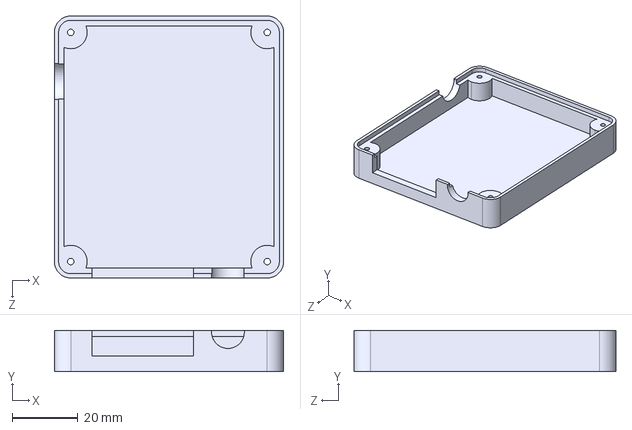
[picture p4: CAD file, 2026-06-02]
CAD/v2/SkiSafe CamelBack 02 - TOP.STEP
70.0 x 12.6 x 80.0 mm

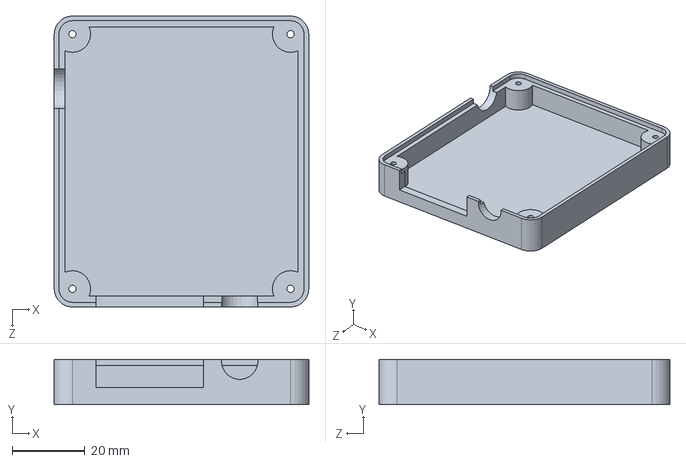
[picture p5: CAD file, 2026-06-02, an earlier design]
CAD/v1/SkiSafe CamelBack 01.SLDPRT
70.0 x 12.4 x 80.0 mm

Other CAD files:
CAD/v2/SkiSafe CamelBack 02.SLDPRT
CAD/v2/SkiSafe 02.SLDPRT
CAD/v1/SkiSafe 01 - Front.STEP
CAD/v1/SkiSafe 01.SLDPRT
CAD/v1/SkiSafe 01 - Back.STEP
CAD/v1/SkiSafe CamelBack 01 BASE.STEP
CAD/v1/SkiSafe CamelBack 01 - TOP.STEP

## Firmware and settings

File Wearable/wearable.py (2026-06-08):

# =============================================================================
#  SkiSafe — Wearable Node Production Firmware
#  File   : wearable.py   (flash as main.py)
#  Board  : Pycom LoPy4 standalone (no expansion board)
#  Runtime: Pycom MicroPython 1.20.2.r6
# =============================================================================
#
#  AUTHORITATIVE PIN MAP  (verified by Full-Hardware_Test.py — do not change):
#    P2   OUT   Green LED        Alert L0 normal / steady ON
#    P3   OUT   Yellow LED       Alert L1 warning / L3 SOS rapid flash
#    P4   OUT   Red LED          Alert L2 fall    / L3 SOS rapid flash
#    P9   I2C   SDA              Hardware SDA — shared bus (MPU-6050 + BH1750)
#    P10  I2C   SCL              Hardware SCL
#    P21  OUT   Passive buzzer   Active HIGH
#    P22  IN    Dismiss button   PULL_UP, active LOW  (idle HIGH, press LOW)
#    P14  ADC   NTC thermistor   ATTN_11DB; 3V3->10k->P14->10k NTC->GND
#    P15  ADC   Battery divider  ATTN_11DB; LiPo+->100k->P15->100k->GND
#    P19  RX    GPS UART1        NEO-6M TX->P19, 9600 baud, receive only
#    P0/P1      UART0 console    Default REPL — not initialised in firmware
#
#  I2C DEVICES (verified scan):
#    MPU-6050 @ 0x68  (AD0 -> GND)
#    BH1750   @ 0x23  (ADDR confirmed by hardware scan — NOT 0x46)
#
#  CRITICAL POWER RULE — read before every hardware session:
#    PowerBoost 5V -> LoPy4 VIN ONLY.
#    Every sensor, LED, buzzer, and GPS module runs from LoPy4 3V3.
#    Applying 5V to any GPIO or sensor pin WILL destroy it.
#    The NEO-6M GPS was destroyed once by 5V — do not repeat.
#
#  PYCOM MICROPYTHON CONSTRAINTS — enforced throughout:
#    No f-strings  ->  use string concatenation
#    Use utime     ->  not time
#    Use ujson     ->  not json
#    No walrus, no match/case, no structural pattern matching
#
#  FLASH COMMAND (Windows — adjust COM port):
#    uvx mpremote connect COM10 cp Wearable/wearable.py :main.py + reset + repl
# =============================================================================

from machine import Pin, I2C, ADC, UART
from network import LoRa
import socket
import utime
import math
import ujson
import gc


# =============================================================================
#  SECTION 1 — CONFIGURATION
#  All tuneable parameters in one place — safe to edit.
# =============================================================================

# ── Device identity ───────────────────────────────────────────────────────────
SKIER_ID = 'SK01'

# ── LoRa link (must match receiver.py exactly) ─────────────────────────
LORA_FREQUENCY = 915000000   # Hz — 915 MHz AU915 band
LORA_SF        = 7           # Spreading factor  (7 = fastest / lowest range)

# ── Telemetry timing (from wearable.py: SEND_INTERVAL_MS = 5000) ─────────
TELEMETRY_INTERVAL_MS = 5000   # Normal TX cadence (ms)
FAST_TX_INTERVAL_MS   = 2000   # TX cadence when alert level >= 2 (ms)
LOOP_SLEEP_MS         = 20     # Main loop yield — keeps IMU sampling near 50 Hz
GC_INTERVAL_MS        = 60000  # Periodic garbage collection (ms)
WARMUP_MS             = 15000  # ms before first TX and alert activation (prevents false alarms on boot)
L2_ACK_TIMEOUT_MS     = 60000  # ms before unacknowledged L2 escalates to L3

# ── Alert thresholds (match wearable.py and wearable.py exactly) ───
FALL_MAG_THRESHOLD  = 35000   # Raw IMU units — sudden spike -> fall
MOTION_BAND_LOW     = 14000   # Below this: unusual low-g (free fall / tumble)
MOTION_BAND_HIGH    = 18000   # Above this: movement / normal vibration
IMMOBILITY_L1_SECS  = 30      # Immobile this long -> L1 warning
IMMOBILITY_L2_SECS  = 60      # Immobile this long -> L2 alert
IMMOBILITY_L3_SECS  = 120     # Fall + immobile this long -> L3 SOS
FALL_LATCH_MS       = 300000  # Fall holds L2 minimum for 5 minutes (ms)

SKIN_TEMP_L1_C      = 15.0    # C  below this -> L1 cold warning
SKIN_TEMP_L3_C      = 10.0    # C  below this -> L3 critical cold
BURIAL_LUX          = 10.0    # lux — darkness threshold for burial detection
BATTERY_L1_PCT      = 20      # %  below this -> L1 battery warning

# ── GPS ───────────────────────────────────────────────────────────────────────
GPS_STALE_MS = 30000   # ms after last fix before GPS data is zeroed in packet

# ── Buzzer patterns: (on_ms, off_ms) per alert level ─────────────────────────
#    From wearable.py — proven on hardware.
BUZ_PATTERNS = {
    1: (100, 1900),   # Gentle single beep — cold / battery warning
    2: (300,  700),   # Urgent — fall detected
    3: (200,  200),   # Rapid SOS — burial / critical
}

# ── LED flash timing for L3 SOS (from hardware test test_leds: 120ms) ────────
LED_FLASH_MS = 120   # on/off half-period for yellow + red SOS flash

# ── Rolling average buffer depths ────────────────────────────────────────────
BUF_LIGHT = 3   # ~15 s at 5 s cadence
BUF_TEMP  = 5   # ~25 s
BUF_GPS   = 3   # ~15 s

# ── Button debounce ───────────────────────────────────────────────────────────
DEBOUNCE_MS = 50


# =============================================================================
#  SECTION 2 — CONSTANTS
#  Verified hardware values — these match the physical build.  Do not change
#  without corresponding hardware rework and re-verification.
# =============================================================================

# ── Pin names ─────────────────────────────────────────────────────────────────
PIN_LED_GREEN  = 'P2'
PIN_LED_YELLOW = 'P3'
PIN_LED_RED    = 'P4'
PIN_I2C_SDA    = 'P9'
PIN_I2C_SCL    = 'P10'
PIN_BUTTON     = 'P22'
PIN_BUZZER     = 'P21'
PIN_NTC_ADC    = 'P14'
PIN_BATT_ADC   = 'P15'
PIN_GPS_RX     = 'P19'

# ── I2C addresses (confirmed by hardware scan) ────────────────────────────────
MPU6050_ADDR = 0x68   # AD0 -> GND
BH1750_ADDR  = 0x23   # Hardware scan confirmed — NOT 0x46

# ── MPU-6050 register addresses ───────────────────────────────────────────────
MPU_PWR_MGMT_1 = 0x6B
MPU_ACCEL_CFG  = 0x1C
MPU_ACCEL_XOUT = 0x3B
MPU_ACCEL_LSB  = 16384.0   # LSB per g at default +/-2g range

# ── BH1750 command bytes (init sequence verified by Full-Hardware_Test.py) ────
BH1750_POWER_ON   = 0x01   # Must send BEFORE continuous-mode command
BH1750_CONT_HIRES = 0x10   # Continuous high-res mode (~120-180 ms/sample)
BH1750_LUX_DIV    = 1.2    # raw counts -> lux

# ── ADC / NTC — proven 3.3 V reference convention from hardware test ──────────
ADC_FULL_SCALE = 4095.0
ADC_VREF       = 3.3      # Verified reference voltage for all ADC formulas
NTC_SERIES_R   = 10000.0  # Fixed series resistor (3V3 side)
NTC_NOMINAL_R  = 10000.0  # NTC nominal resistance at 25 C
NTC_NOMINAL_T  = 25.0     # Celsius
NTC_BETA       = 3950.0
NTC_RAW_MIN    = 10       # <= this: open or short fault
NTC_RAW_MAX    = 4085     # >= this: open or short fault

# ── Battery divider ───────────────────────────────────────────────────────────
BATT_DIVIDER = 2.0    # V_bat = V_pin * 2 (two equal 100 k resistors)
BATT_FULL_V  = 4.2    # Full charge
BATT_EMPTY_V = 3.3    # Empty
BATT_OK_LOW  = 3.0    # Below this: likely no battery, skip reading
BATT_OK_HIGH = 4.3    # Above this: impossible, skip reading

# ── Lux sentinel ─────────────────────────────────────────────────────────────
LUX_UNAVAILABLE = -1.0   # Returned / cached when BH1750 has no valid reading


# =============================================================================
#  HARDWARE INITIALISATION
#  Every device is wrapped in try/except.  A failed device sets its flag to
#  False; the rest of the firmware checks that flag before using the device.
# =============================================================================

print('')
print('SkiSafe ' + SKIER_ID + ' — Pycom MicroPython 1.20.2.r6')
print('Initialising hardware...')
print('')

# ── GPIO outputs (LEDs and buzzer) ───────────────────────────────────────────
led_green  = Pin(PIN_LED_GREEN,  mode=Pin.OUT, value=0)
led_yellow = Pin(PIN_LED_YELLOW, mode=Pin.OUT, value=0)
led_red    = Pin(PIN_LED_RED,    mode=Pin.OUT, value=0)
buzzer     = Pin(PIN_BUZZER,     mode=Pin.OUT, value=0)

# ── GPIO input (dismiss button) ───────────────────────────────────────────────
button = Pin(PIN_BUTTON, mode=Pin.IN, pull=Pin.PULL_UP)   # idle HIGH, press LOW

# ── I2C shared bus ────────────────────────────────────────────────────────────
# Hardware SDA = P9, SCL = P10.  Verified final build.  NOT P21/P22.
_i2c = None
_i2c_found = []
try:
    _i2c = I2C(0, pins=(PIN_I2C_SDA, PIN_I2C_SCL))
    utime.sleep_ms(50)
    _i2c_found = _i2c.scan()
    print('I2C scan    : ' + str([hex(d) for d in _i2c_found]))
except Exception as _e:
    print('I2C FATAL   : ' + str(_e))
    _i2c = None
    _i2c_found = []

# ── MPU-6050  (accelerometer / fall detection) ────────────────────────────────
# Wake from sleep: write 0x00 to PWR_MGMT_1 (0x6B).
# Set accelerometer to +/-2g range: write 0x00 to ACCEL_CONFIG (0x1C).
# Both steps verified by Full-Hardware_Test.py test_mpu6050().
_mpu_ok = False
if _i2c is not None and MPU6050_ADDR in _i2c_found:
    try:
        _i2c.writeto_mem(MPU6050_ADDR, MPU_PWR_MGMT_1, bytes([0x00]))
        utime.sleep_ms(50)
        _i2c.writeto_mem(MPU6050_ADDR, MPU_ACCEL_CFG, bytes([0x00]))
        _mpu_ok = True
        print('MPU-6050    : OK  (0x68)  fall detection enabled')
    except Exception as _e:
        print('MPU-6050    : FAILED  ' + str(_e) + '  (fall detection degraded)')
else:
    print('MPU-6050    : NOT FOUND  (fall detection degraded)')

# ── BH1750  (ambient light / burial detection) ────────────────────────────────
# Init sequence verified by Full-Hardware_Test.py test_bh1750():
#   1. Send POWER_ON  (0x01) — some chips skip ACK here; that is non-fatal.
#   2. Wait 10 ms.
#   3. Send CONT_HIRES (0x10) — starts continuous high-resolution measurement.
#   4. Wait 180 ms for the first conversion to complete.
# Without the power-on step, first reads may return 0 or 65535.
_bh1750_ok = False
_bh1750_errors = 0
if _i2c is not None and BH1750_ADDR in _i2c_found:
    try:
        try:
            _i2c.writeto(BH1750_ADDR, bytes([BH1750_POWER_ON]))
            utime.sleep_ms(10)
        except Exception:
            pass   # Power-on ACK not always reliable — not fatal
        _i2c.writeto(BH1750_ADDR, bytes([BH1750_CONT_HIRES]))
        utime.sleep_ms(180)
        _bh1750_ok = True
        print('BH1750      : OK  (0x23)  burial detection enabled')
    except Exception as _e:
        print('BH1750      : FAILED  ' + str(_e) + '  (burial detection degraded)')
else:
    print('BH1750      : NOT FOUND  (burial detection degraded)')

# ── ADC channels ─────────────────────────────────────────────────────────────
_adc      = ADC()
_ntc_ch   = _adc.channel(pin=PIN_NTC_ADC,  attn=ADC.ATTN_11DB)
_batt_ch  = _adc.channel(pin=PIN_BATT_ADC, attn=ADC.ATTN_11DB)
print('ADC         : OK  NTC=P14  Battery=P15  ATTN_11DB')

# ── GPS UART ─────────────────────────────────────────────────────────────────
# UART1, 9600 8N1, receive-only.
# pins=(TX, RX): TX=None — GPS RX line left disconnected (not needed).
# Verified syntax from Full-Hardware_Test.py test_gps().
_gps_uart = None
try:
    _gps_uart = UART(1, baudrate=9600, pins=(None, PIN_GPS_RX))
    print('GPS UART    : OK  UART1  P19=RX  9600 baud  receive-only')
except Exception as _e:
    print('GPS UART    : FAILED  ' + str(_e))

# ── LoRa radio ────────────────────────────────────────────────────────────────
# Config must match receiver.py exactly.
# LoRa.ALWAYS_ON keeps the radio ready to receive downlink ACKs between TXs.
_lora_sock = None
_lora_ok   = False
try:
    _lora = LoRa(
        mode        = LoRa.LORA,
        region      = LoRa.AU915,
        frequency   = LORA_FREQUENCY,
        bandwidth   = LoRa.BW_125KHZ,
        sf          = LORA_SF,
        preamble    = 8,
        coding_rate = LoRa.CODING_4_5,
        power_mode  = LoRa.ALWAYS_ON,
    )
    _lora_sock = socket.socket(socket.AF_LORA, socket.SOCK_RAW)
    _lora_sock.setblocking(False)
    _lora_ok = True
    print('LoRa        : OK  ' + str(LORA_FREQUENCY // 1000000) + ' MHz  SF' + str(LORA_SF) + '  ALWAYS_ON')
except Exception as _e:
    print('LoRa        : FATAL  ' + str(_e))
    _lora_ok = False

print('')


# =============================================================================
#  SECTION 4 — GPS PROCESSING
#  Non-blocking character-by-character UART drain.
#  Parses GNRMC / GPRMC (position + speed) and GNGGA / GPGGA (altitude + sats).
#  GPS globals are updated in-place; stale check uses ticks_ms.
# =============================================================================

_gps_rx_buf  = b''         # Accumulates bytes until \n or \r
_gps_fix_ms  = 0           # ticks_ms of last valid fix (0 = never)

gps_lat   = 0.0
gps_lon   = 0.0
gps_alt   = 0.0
gps_speed = 0.0
gps_fix   = False
gps_sats  = 0


def _nmea_to_decimal(raw, hemi):
    """Convert NMEA DDDMM.MMMM + hemisphere character to signed decimal degrees."""
    try:
        dot  = raw.index('.')
        deg  = int(raw[:dot - 2])
        mins = float(raw[dot - 2:])
        dec  = deg + mins / 60.0
        if hemi in ('S', 'W'):
            dec = -dec
        return dec
    except Exception:
        return None


def _parse_nmea(sentence):
    """
    Parse one complete NMEA sentence (stripped, no CRLF) and update GPS globals.
    Handles: $GPRMC $GNRMC $GPGGA $GNGGA.
    All exceptions are silently swallowed — malformed sentences are discarded.
    """
    global gps_lat, gps_lon, gps_alt, gps_speed, gps_fix, gps_sats, _gps_fix_ms

    if not sentence.startswith('$'):
        return

    # Strip NMEA checksum (*HH)
    if '*' in sentence:
        sentence = sentence[:sentence.index('*')]

    fields = sentence.split(',')
    if not fields:
        return
    msg = fields[0]

    # RMC — recommended minimum: position, speed, validity flag
    if msg in ('$GPRMC', '$GNRMC') and len(fields) >= 8:
        if fields[2] == 'A':   # 'A' = data valid,  'V' = void / no fix
            lat = _nmea_to_decimal(fields[3], fields[4])
            lon = _nmea_to_decimal(fields[5], fields[6])
            if lat is not None and lon is not None:
                gps_lat  = lat
                gps_lon  = lon
                gps_fix  = True
                _gps_fix_ms = utime.ticks_ms()
            try:
                gps_speed = float(fields[7]) * 1.852   # knots -> km/h
            except Exception:
                gps_speed = 0.0
        else:
            gps_fix = False

    # GGA — fix data: altitude, satellite count, fix quality indicator
    elif msg in ('$GPGGA', '$GNGGA') and len(fields) >= 10:
        try:
            s = fields[7].strip()
            if s:
                gps_sats = int(s)
        except Exception:
            pass
        
        if fields[6] not in ('', '0') and fields[9].strip():
            try:
                gps_alt = float(fields[9])
            except Exception:
                pass


def update_gps():
    """
    Drain all available bytes from the GPS UART and parse complete NMEA sentences.
    Non-blocking — returns immediately when the RX buffer is empty.
    A 128-byte hard limit on the accumulation buffer guards against runaway growth
    if the GPS sends non-terminated data (e.g. at power-on).
    """
    global _gps_rx_buf
    if _gps_uart is None:
        return
    while _gps_uart.any():
        ch = _gps_uart.read(1)
        if ch is None:
            break
        if ch in (b'\n', b'\r'):
            if _gps_rx_buf:
                try:
                    _parse_nmea(_gps_rx_buf.decode('ascii', 'ignore').strip())
                except Exception:
                    pass
                _gps_rx_buf = b''
        else:
            _gps_rx_buf += ch
            if len(_gps_rx_buf) > 128:
                _gps_rx_buf = b''   # Overflow guard


def gps_is_fresh(now_ms):
    """Return True if the last valid GPS fix is less than GPS_STALE_MS old."""
    if not gps_fix or _gps_fix_ms == 0:
        return False
    return utime.ticks_diff(now_ms, _gps_fix_ms) < GPS_STALE_MS


# =============================================================================
#  SECTION 5 — ACCELEROMETER PROCESSING  (MPU-6050)
#  Direct register reads — no driver object needed.
#  Falls back to 1g resting value if the IMU is unavailable or errors.
# =============================================================================

def read_imu_magnitude():
    """
    Read the MPU-6050 acceleration vector magnitude in raw 16-bit units.
    At rest, magnitude ~= 16384 (1g at ±2g range, 16384 LSB/g).
    Fall detection threshold is 35000 raw units (~2.1g sudden spike).
    Returns 16384.0 (safe 1g default) on any error or if IMU is absent.
    """
    if not _mpu_ok or _i2c is None:
        return 16384.0
    try:
        d  = _i2c.readfrom_mem(MPU6050_ADDR, MPU_ACCEL_XOUT, 6)
        ax = (d[0] << 8) | d[1]
        ay = (d[2] << 8) | d[3]
        az = (d[4] << 8) | d[5]
        if ax > 32767: ax -= 65536
        if ay > 32767: ay -= 65536
        if az > 32767: az -= 65536
        return math.sqrt(ax * ax + ay * ay + az * az)
    except Exception:
        return 16384.0


# =============================================================================
#  SECTION 6 — LIGHT SENSOR  (BH1750)
#  Sensor runs in continuous high-resolution mode set at initialisation.
#  Returns LUX_UNAVAILABLE (-1.0) on read failure.
#  Auto-recovery: after 5 consecutive errors, attempts to re-send the
#  continuous-mode command so a transient I2C glitch does not permanently
#  disable burial detection.
# =============================================================================

def read_lux():
    """
    Read ambient illuminance from BH1750 (lux, float).
    Returns LUX_UNAVAILABLE (-1.0) if the sensor is absent or read fails.
    """
    global _bh1750_ok, _bh1750_errors
    if not _bh1750_ok or _i2c is None:
        return LUX_UNAVAILABLE
    try:
        data = _i2c.readfrom(BH1750_ADDR, 2)
        raw  = (data[0] << 8) | data[1]
        _bh1750_errors = 0
        return raw / BH1750_LUX_DIV
    except Exception:
        _bh1750_errors += 1
        if _bh1750_errors >= 5:
            # Attempt to restore continuous mode after repeated failures
            try:
                try:
                    _i2c.writeto(BH1750_ADDR, bytes([BH1750_POWER_ON]))
                    utime.sleep_ms(10)
                except Exception:
                    pass
                _i2c.writeto(BH1750_ADDR, bytes([BH1750_CONT_HIRES]))
                utime.sleep_ms(180)   # Blocking — acceptable on rare recovery path
                _bh1750_errors = 0
                print('BH1750: continuous mode re-sent after read errors')
            except Exception:
                pass
        return LUX_UNAVAILABLE


# =============================================================================
#  SECTION 7 — TEMPERATURE AND BATTERY READING
# =============================================================================

def read_skin_temp():
    """
    Read skin temperature via NTC thermistor on P14.
    Circuit: 3V3 -> 10k (series) -> P14 -> 10k NTC -> GND.
    NTC is on the GND side of the divider.

    Formula proven by Full-Hardware_Test.py test_ntc_temperature():
      voltage = raw / 4095.0 * 3.3
      r_ntc   = R_SERIES * voltage / (3.3 - voltage)
      T (K)   = 1 / (1/T_nominal + ln(r_ntc/R_nominal) / Beta)

    Averages 8 ADC samples to reduce noise (adds ~16 ms blocking per read;
    acceptable — only called on TX cadence, not every tick).

    Returns temperature in Celsius, or -99.0 as a fault sentinel.
    """
    total = 0
    for _ in range(8):
        total += _ntc_ch.value()
        utime.sleep_ms(2)
    raw = total >> 3   # integer divide by 8

    if raw <= NTC_RAW_MIN or raw >= NTC_RAW_MAX:
        return -99.0   # Open circuit or short

    voltage = raw / ADC_FULL_SCALE * ADC_VREF
    if voltage >= ADC_VREF:
        return -99.0

    r_ntc = NTC_SERIES_R * voltage / (ADC_VREF - voltage)

    try:
        inv_t = ((1.0 / (NTC_NOMINAL_T + 273.15))
                 + math.log(r_ntc / NTC_NOMINAL_R) / NTC_BETA)
        return (1.0 / inv_t) - 273.15
    except Exception:
        return -99.0


def read_battery():
    """
    Read battery voltage and charge percentage via voltage divider on P15.
    Circuit: LiPo+ -> 100k -> P15 -> 100k -> GND  =>  V_P15 = V_bat / 2.

    Averages 16 samples to suppress ADC noise (adds ~32 ms).
    Called on TX cadence only.

    Returns (voltage_volts, percent_int).
    Returns (0.0, 0) when the reading is outside the plausible 3.0-4.3 V range
    (e.g. no cell connected, or USB power only).
    """
    total = 0
    for _ in range(16):
        total += _batt_ch.value()
        utime.sleep_ms(2)
    raw   = total >> 4              # divide by 16
    v_pin = raw / ADC_FULL_SCALE * ADC_VREF
    v_bat = v_pin * BATT_DIVIDER

    if v_bat < BATT_OK_LOW or v_bat > BATT_OK_HIGH:
        return 0.0, 0

    pct = int((v_bat - BATT_EMPTY_V) / (BATT_FULL_V - BATT_EMPTY_V) * 100)
    if pct < 0:   pct = 0
    if pct > 100: pct = 100
    return v_bat, pct


# =============================================================================
#  SECTION 8 — ROLLING AVERAGE HELPERS
#  Each sensor maintains a small FIFO buffer.  Averages smooth noisy readings
#  without introducing long blocking windows.
# =============================================================================

_lux_buf   = []
_temp_buf  = []
_lat_buf   = []
_lon_buf   = []
_alt_buf   = []
_speed_buf = []


def _avg(buf):
    """Return the mean of a list, or 0.0 if empty."""
    return sum(buf) / len(buf) if buf else 0.0


def _push(buf, val, maxlen):
    """Append val to buf, discarding the oldest entry when full."""
    buf.append(val)
    if len(buf) > maxlen:
        buf.pop(0)
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

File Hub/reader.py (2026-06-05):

#!/usr/bin/env python3
"""
SkiSafe — reader.py
Reads serial output from the hub LoPy4 (receiver.py), parses the short-key
JSON telemetry packets, maps to full field names, inserts into SQLite, and creates
alert_log entries when the wearable reports a level ≥ 2 event.

Changes from reader.py:
  • Added 'bt' -> 'battery_pct' to KEY_MAP
  • Added battery_pct REAL column to sensor_log (CREATE TABLE + migration)
  • insert_reading() now writes battery_pct
  • Console RX line includes battery percentage

Sessions:
    A new session is opened when reader.py starts, or when no packet
    has been received for SESSION_GAP_S seconds (default 120).  Every sensor_log and
    alert_log row carries the current session_id so the review page can show
    historical sessions independently.

Run: python3 ~/skisafe/reader.py

The hub LoPy4 (via Pytrack USB) prints lines like:
    Received: {"i":"SK01","c":5,"st":20.3,"lx":240,"la":-37.84,"lo":144.96,"al":523,"sp":12.3,"bt":87,"a":0}
    RSSI: -72
    SNR: 8.5

Short-key → full-name mapping (must match wearable firmware):
    i  = skier_id        (string)
    c  = packet_count    (int)
    st = skin_temp       (float, °C)
    lx = light           (float, lux)
    la = lat             (float, decimal degrees)
    lo = lon             (float)
    al = altitude        (float, metres)
    sp = speed           (float, km/h)
    bt = battery_pct     (int, 0-100)
    a  = alert           (int, 0-3)
"""

import serial
import sqlite3
import json
import time
import os
import sys
from datetime import datetime

# ── Configuration ─────────────────────────────────────────────────────────────
SERIAL_PORT   = os.environ.get('SKISAFE_PORT', '/dev/ttyACM0')
SERIAL_BAUD   = 115200
DB_PATH       = os.path.expanduser(os.environ.get('SKISAFE_DB', '~/skisafe/skisafe.db'))
SESSION_GAP_S = int(os.environ.get('SESSION_GAP_S', '120'))   # seconds gap → new session

# ── Short-key to full-name map ─────────────────────────────────────────────────
KEY_MAP = {
    'i':  'skier_id',
    'c':  'packet_count',
    'st': 'skin_temp',
    'lx': 'light',
    'la': 'lat',
    'lo': 'lon',
    'al': 'altitude',
    'sp': 'speed',
    'bt': 'battery_pct',
    'a':  'alert',
}

# ── Session state ──────────────────────────────────────────────────────────────
_current_session_id  = None
_last_packet_epoch   = 0.0


# ── Database setup ─────────────────────────────────────────────────────────────
def init_db(path):
    """Create / migrate tables.  Idempotent — safe to call on every start."""
    conn = sqlite3.connect(path, timeout=10)
    conn.row_factory = sqlite3.Row
    conn.execute('PRAGMA journal_mode=WAL')
    conn.execute('PRAGMA synchronous=NORMAL')

    conn.executescript('''
        CREATE TABLE IF NOT EXISTS sessions (
            id           INTEGER PRIMARY KEY AUTOINCREMENT,
            start_ts     TEXT    NOT NULL,
            end_ts       TEXT,
            skier_id     TEXT,
            start_epoch  REAL    NOT NULL
        );

        CREATE TABLE IF NOT EXISTS sensor_log (
            id           INTEGER PRIMARY KEY AUTOINCREMENT,
            session_id   INTEGER REFERENCES sessions(id),
            ts           TEXT    NOT NULL,
            skier_id     TEXT,
            packet_count INTEGER,
            skin_temp    REAL,
            light        REAL,
            lat          REAL,
            lon          REAL,
            altitude     REAL,
            speed        REAL,
            alert        INTEGER DEFAULT 0,
            rssi         INTEGER,
            snr          REAL,
            battery_pct  REAL
        );

        CREATE TABLE IF NOT EXISTS alert_log (
            id            INTEGER PRIMARY KEY AUTOINCREMENT,
            session_id    INTEGER REFERENCES sessions(id),
            ts            TEXT    NOT NULL,
            created_epoch REAL    NOT NULL,
            skier_id      TEXT,
            level         INTEGER,
            lat           REAL,
            lon           REAL,
            message       TEXT,
            acknowledged  INTEGER DEFAULT 0,
            ack_ts        TEXT,
            ack_by        TEXT,
            escalated     INTEGER DEFAULT 0,
            email_sent    INTEGER DEFAULT 0
        );
    ''')
    conn.commit()

    # ── Migration: add missing columns to existing tables ─────────────────────
    cols = [r[1] for r in conn.execute('PRAGMA table_info(sensor_log)').fetchall()]
    if 'session_id' not in cols:
        conn.execute('ALTER TABLE sensor_log ADD COLUMN session_id INTEGER')
        conn.commit()
        print('[db] Migrated sensor_log — added session_id column')
    if 'battery_pct' not in cols:
        conn.execute('ALTER TABLE sensor_log ADD COLUMN battery_pct REAL')
        conn.commit()
        print('[db] Migrated sensor_log — added battery_pct column')

    cols_al = [r[1] for r in conn.execute('PRAGMA table_info(alert_log)').fetchall()]
    if 'session_id' not in cols_al:
        conn.execute('ALTER TABLE alert_log ADD COLUMN session_id INTEGER')
        conn.commit()
        print('[db] Migrated alert_log — added session_id column')

    return conn


# ── Session management ─────────────────────────────────────────────────────────
def get_or_create_session(conn, skier_id):
    """
    Return the current session_id.
    Opens a new session when:
      - reader.py just started (no session yet), OR
      - more than SESSION_GAP_S seconds have passed since the last packet.
    """
    global _current_session_id, _last_packet_epoch

    now = time.time()
    gap = now - _last_packet_epoch

    if _current_session_id is None or gap > SESSION_GAP_S:
        ts = datetime.now().isoformat()
        cur = conn.execute(
            'INSERT INTO sessions (start_ts, start_epoch, skier_id) VALUES (?,?,?)',
            (ts, now, skier_id)
        )
        conn.commit()
        _current_session_id = cur.lastrowid
        reason = 'first packet' if gap > 9e8 else ('gap of ' + str(int(gap)) + 's')
        print('[session] New session #' + str(_current_session_id) +
              ' started for ' + skier_id + ' (' + reason + ')')

    _last_packet_epoch = now
    return _current_session_id


def touch_session(conn, session_id):
    """Update the session end_ts to now (called after every inserted packet)."""
    conn.execute(
        'UPDATE sessions SET end_ts=? WHERE id=?',
        (datetime.now().isoformat(), session_id)
    )


# ── Helpers ────────────────────────────────────────────────────────────────────
def make_alert_message(data):
    level = data.get('alert', 0)
    msgs  = []
    if level >= 2:
        msgs.append('Fall detected (IMU threshold exceeded)')
    if data.get('skin_temp', 99) < 15:
        msgs.append('Low skin temperature: ' + str(data.get('skin_temp', '?')) + ' C')
    if data.get('light', 99) < 10:
        msgs.append('Possible burial (very low light + immobility)')
    return '; '.join(msgs) if msgs else 'Alert level ' + str(level)
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

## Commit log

2026-05-31 feat: GPS standalone test confirmed — correct P19/P20 wiring, NMEA diagnostic output Updated GPS_test.py with proper UART pin order (P20=TX unused, P19=RX), full NMEA parser with fix detection, and d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
2026-05-31 feat: GPS integrated into wearable firmware + complete hub stack wearable_final.py (v6): GPS integrated, inline MPU-6050/BH1750 drivers, full 3-tier alert system (fall/cold/burial), non-blocking buzz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
    [app.py, reader.py]
2026-06-01 feat: polished dashboard/review templates + updated app.py API Hub/templates/dashboard.html: live sensor cards, canvas GPS tracker with heading arrow + compass, alert log, status badge with SOS pulse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
    [app.py]
2026-06-01 feat: add Pi management scripts — start/stop/status hub + update
2026-06-01 feat: add wearable simulator for hub testing — no sensors required
2026-06-01 fix: receiver recv(64) → recv(256) — GPS packets were splitting across two reads causing parse errors
    [receiver_final.py]
2026-06-01 feat: replace canvas GPS tracker with Leaflet.js + OpenStreetMap - Swap custom canvas draw loop for Leaflet map with OSM tiles - Live polyline trail via trailLine.setLatLngs() on each poll - Pulsing 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
2026-06-01 feat: session tracking, persistent GPS trail, Leaflet review map - reader.py: sessions table, session_id on all rows, 2-min gap detection - app.py: /api/sessions endpoint, session_id filter on /api/h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
    [app.py, reader.py]
2026-06-02 docs: comprehensive pinout reference for wearable node - All LoPy4 pins with direction, connected component, signal name and notes - I2C shared bus diagram (MPU-6050 0x68 + BH1750 0x23) - NEO-6M GPS 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
2026-06-02 feat: add CAD enclosure designs v1 and v2 (wearable + CamelBak) - Wearable main body: front/back STEP exports + SolidWorks part - CamelBak attachment: top/base STEP exports + SolidWorks part - Both v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
    [SkiSafe 01 - Back.STEP, SkiSafe 01 - Front.STEP, SkiSafe 01.SLDPRT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]
2026-06-05 Add battery support: reader + dashboard
